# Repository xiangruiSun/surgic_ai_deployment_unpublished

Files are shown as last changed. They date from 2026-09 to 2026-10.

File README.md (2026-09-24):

# Autonomous Suturing on the dVRK: from SurgicAI policies to a real PSM

> 📄 **Draft paper (prepared for publication, not yet peer reviewed):**
> [*Autonomous Suturing Task: From Hierarchical Policies in Simulation to a Guarded Needle-Handling Pipeline on a Real dVRK*](paper/surgical_rl_draft.pdf)
> — Xiangrui Sun‡, Jiaming Wen‡, Adnan Munawar\*, Anqi Liu\* (‡equal contribution, co-first authors; \*corresponding authors). Sources and figures in [`paper/`](paper/README.md).

This repository takes the reinforcement-learning suturing policies of
[SurgicAI](https://github.com/surgical-robotics-ai/SurgicAI) (NeurIPS 2024) and
runs them on a real da Vinci Research Kit PSM. It contains the real-robot
deployment, the grasp calibration, the simulation environments used to train
and retrain the policies, and the draft paper.

## The pipeline

```text
 PERCEPTION (real endoscope)                        separate repository, see below
   ECM RGB ─► Depth Anything V2 (sim-fine-tuned, metric) ─► depth
   RGB + mask + depth ─► FoundationPose ─► needle pose  ᶜT_N
   ArUco marker on the PSM shaft ─► hand-eye  ᴱT_C

 GRASP TARGET                                       deploy/surgicai_rl_deploy/calib/
   coarse:  ᴱT_C · ᶜT_N · T_grasp   (needle point 30° along the arc, not the mesh origin)
   fine:    + Bernstein residual field learned from taught grasps (affine → degree n)
   refuses outside the calibrated box, on a pose flip, or on changed conventions

 REAL-ROBOT SEQUENCE                                deploy/run_pipeline.py
   precheck (fail-closed) ─► stage ─► approach ─► descend 7 mm ─► settle ─► close jaw
        ─► observe ─► operator gate ─► lift 1.5 cm ─► transport (via point) ─► place ─► hold
   approach:  RL checkpoint (through the verified contract) or D2 SE(3) servo
   abort:     hold the last command, never open the jaw

 SIMULATION                                         src/SurgicAI/RL/ + SurgicAI fork
   AMBF + SRC ─► SurgicAI subtask envs ─► TD3+HER+BC policies ─► checkpoints
   hierarchical 5-stage chain replicated on ROS 2 / AMBF 3 (11/20 full sutures, paper: 52%)
```

The same `GraspLiftSequencer` drives both the real arm and the AMBF grasp-and-lift
environment, so what is rehearsed in simulation is the code that runs on the robot.

## Where things are

| Part | Location | Notes |
|---|---|---|
| Real-robot pipeline | [`deploy/`](deploy/) | ROS 2 entry points, phase machine, safety, tools; 588 tests with no ROS, robot or checkpoint |
| Full pipeline guide | [`deploy/README_GRASP_LIFT.md`](deploy/README_GRASP_LIFT.md) | stage → … → place, operator gate, safety envelope |
| Approach-only guide | [`deploy/README.md`](deploy/README.md) | `run_approach.py`, frame modes, contract |
| Grasp calibration | [`deploy/README_CALIBRATION.md`](deploy/README_CALIBRATION.md) | FoundationPose + hand-eye + Bernstein residual |
| Simulation / training | [`src/SurgicAI/RL/`](src/SurgicAI/RL/) | Approach and GraspLift envs, TD3/SAC/PPO(+BC,+HER), curriculum |
| Retraining plan | [`src/SurgicAI/RL/RETRAINING.md`](src/SurgicAI/RL/RETRAINING.md) | what retraining buys, and what it does not |
| Needle model | [`asset/`](asset/) | 20 mm, 135° needle STL used for pose estimation |
| Draft paper | [`paper/`](paper/) | PDF, LaTeX, figure script, rehearsal traces |
| Hierarchical replication | [xiangruiSun/SurgicAI @ `jin-hierarchical-repro`](https://github.com/xiangruiSun/SurgicAI/tree/jin-hierarchical-repro) | Jin Wu's 5-stage pipeline on ROS 2; needs the full SurgicAI tree and the old SRC |
| Perception (DA, FP) | [suturing-policy-sim2real](https://github.com/18244241528jm-cpu/suturing-policy-sim2real) | Depth Anything fine-tuning, FoundationPose, first-frame gate |

## Things you must know before running anything

These were each found the hard way. Every RL result taken before they were fixed
is void. Details are in the paper (Sec. V) and in `deploy/README_GRASP_LIFT.md`.

1. **Roll branch.** SurgicAI puts roll in **(−2π, 0]**, not SciPy's [−π, π].
   With the wrong branch the upstream Approach policy reproduces 0/25 of its own demonstrations.
2. **Action scale is 1.0 mm / 3°.** The environment metadata's 0.5 mm / 2° is
   the demonstrations' scale, not the policy's. The old 1.5 mm was wrong.
3. **Open-loop observation.** The network sees the integrated *command*, never
   `measured_cp`. Feeding it the measured pose drops Approach to 6/25 on a lagging arm.
4. **The trained goal is 7 mm short of the needle.** The `descend` phase covers
   the last 7 mm; the policy never learned it.
5. **Staging, not retraining.** The real task is outside the policy's trained
   support (0/400 placements). A computed staging move puts all 400/400 inside it.
6. **Deadband.** The PSM ignores small setpoints: 0.4 mm moved it not at all, and
   2 mm moved it 1.947 mm. Measure the deadband with `tools/poke_arm.py` and pass `--min-command-mm`.
7. **Jaw sign.** On the dVRK, a negative jaw angle means squeeze. There is no grasp sensor, so
   jaw evidence is logged with `grasp_verified=false` and the default gate is manual.
8. **QoS.** Subscriptions are BEST_EFFORT. A RELIABLE subscriber misses `jaw/measured_js`.

## Install

Deployment host: Ubuntu 22.04, ROS 2 Humble, Python 3.10.

```bash
git clone <this repository> surgical-rl
cd surgical-rl/deploy
python3 -m venv --system-site-packages .venv-deploy   # keeps rclpy visible
source .venv-deploy/bin/activate
pip install -r requirements-deploy.txt                 # CPU torch is enough
pip install pytest && python3 -m pytest tests -q       # expect 588 passed
```

Checkpoints are not in Git:

```bash
bash tools/fetch_upstream_checkpoints.sh     # upstream Approach + Place, SHA-256 verified
# R6 (r6_unified_single_goal_yaw15_seed1_final.zip) comes from the team; place it under models/rl/
```

Simulation and training need AMBF, the SRC and `requirements/simulation.txt`.
Install a CUDA PyTorch build first.

## Run the pipeline — in this order

All poses are **tool** poses in the frame `measured_cp` reports (`ECM`).

```bash
source /opt/ros/humble/setup.bash
cd deploy

# 0. Is the arm listening, and how big is its deadband?
python3 tools/poke_arm.py --arm /PSM1 --axis x --distance-mm 2 --execute

# 1. Empty-jaw baseline (EMPTY gripper; redo after any tool change)
python3 tools/calibrate_jaw.py --arm /PSM1 --out jaw_baseline.json --execute

# 2. Rehearse offline, including the failures
python3 tools/offline_grasp_lift.py \
  --start-pos <x y z> --start-quat <qx qy qz qw> \
  --grasp-pos <x y z> --suture-pos <x y z> --suture-quat <qx qy qz qw> --suture-confirmed \
  --controller d2 --grasp-standoff-mm 7 --lift-sign -1 --grasp-gate evidence \
  --lag 0.5 --noise-mm 0.2
#   also try: --empty-gripper, --drop-at-step N, --deadband-mm 1.0 --min-command-mm 1.2

# 3. Dry run on the robot (publishes nothing)
python3 run_pipeline.py --grasp-pos <x y z> --suture-pos <x y z> --suture-quat <q> \
  --jaw-baseline jaw_baseline.json --trace dryrun.jsonl

# 4. Empty-gripper rehearsal: same command + --execute --grasp-gate always, nothing under the jaws

# 5. Live, with a human on the gate and a hand on the e-stop
python3 run_pipeline.py --grasp-pos <x y z> --suture-pos <x y z> --suture-quat <q> \
  --suture-confirmed --controller d2 --interface move_cp --rate 2 \
  --lift-sign -1 --jaw-baseline jaw_baseline.json --min-command-mm <measured> \
  --grasp-gate manual --trace live.jsonl --execute
```

To use the RL policy on the approach leg, add `--controller rl --model <zip> --stage`.
To take the grasp target from vision instead of typing it, add
`--needle-pose <FoundationPose estimate> --grasp-calibration <model.json>`
(see `deploy/README_CALIBRATION.md`).

## Useful tools (`deploy/tools/`)

| Tool | Question it answers |
|---|---|
| `verify_contract.py` | Does our observation builder reproduce the checkpoint's stored observations? |
| `replay_demos.py --compare` | Does a checkpoint work through this loop, at which action scale? |
| `profile_checkpoint.py` | What support was the checkpoint trained on? |
| `workspace_spec.py` | Is the task inside the support, and what staging move fixes it? |
| `offline_grasp_lift.py` | Does the whole sequence complete on a lagging, noisy, deadbanded arm? |
| `poke_arm.py` | Does the arm move at all, and what is its deadband? |
| `residual_structure.py` | What should the grasp residual look like before collecting data? |
| `collect_grasp_calibration.py` / `fit_grasp_calibration.py` | Plan, audit and fit a calibration session |

## Status

| | |
|---|---|
| Hierarchy in simulation (ROS 2) | 11/20 full sutures; published result 52% |
| Upstream Approach through our loop | 45/50 of its own demos (published 96 ± 6%) |
| R6 through our loop | 46/50 at 1.0 mm / 3° |
| Full sequence, offline | completes at arm lag 0 / 0.5 / 0.7, final error 0.06–0.10 cm |
| Real robot | bring-up, dry runs, deadband found and handled. **No closed-loop grasp completed yet** |
| Grasp calibration | 10 hardware samples, none usable: eyeballed poses, plus a ~43 mm constant frame offset still to resolve |

## License

MIT for the code in this repository. AMBF, SRC, SurgicAI, FoundationPose, Depth
Anything, meshes and external checkpoints follow their own licenses.

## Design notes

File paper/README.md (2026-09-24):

# Draft paper — Autonomous Suturing Task

> **DRAFT, prepared for publication. Not peer reviewed.** Results, figures and
> text are preliminary and will change. Items marked in red in the PDF
> (`[...]`) are still open.

**[Read the PDF → `surgical_rl_draft.pdf`](surgical_rl_draft.pdf)**

*Autonomous Suturing Task: From Hierarchical Policies in Simulation to a Guarded
Needle-Handling Pipeline on a Real dVRK* — Xiangrui Sun‡, Jiaming Wen‡,
Adnan Munawar\*, Anqi Liu\* (‡equal contribution, co-first authors;
\*corresponding authors).

## What is in it

| Section | Where the work lives |
|---|---|
| Hierarchical SurgicAI pipeline re-run on ROS 2 / AMBF 3 (11/20 full sutures vs. 52% published) | `xiangruiSun/SurgicAI`, branch `jin-hierarchical-repro`, `RL/HIERARCHICAL_README.md` |
| Perception: sim-fine-tuned Depth Anything V2, FoundationPose, ArUco hand-eye | perception pipeline (Jiaming) |
| Deployment contract, the three defects, staging, phase machine, deadband | `deploy/` |
| Two-stage grasp calibration and first hardware samples | `deploy/surgicai_rl_deploy/calib/` |

## Files

```
surgical_rl_draft.pdf    the draft
surgical_rl_draft.tex    source (ieeeconf); needs colors.tex, ieeeconf.cls, figures/
figures/*.tikz           pipeline and phase-machine diagrams (drawn in LaTeX)
figures/*.pdf|png        data figures
make_figures.py          regenerates every data figure
runs/*.json              offline rehearsal traces used by the figures
```

## Rebuild

```bash
# figures (needs numpy, scipy, matplotlib; uses ../deploy)
python3 make_figures.py

# rehearsal traces, if you want to regenerate runs/ too (run from ../deploy)
python3 tools/offline_grasp_lift.py \
  --start-pos -0.05639860616831881 0.03366166453830251 0.024455994074878362 \
  --start-quat 0.23319925218484056 0.4267863636861243 -0.23588767438897446 0.841325450478807 \
  --grasp-pos -0.050726357 0.015332369 0.049514053 \
  --suture-pos -0.040 0.005 0.040 --suture-quat 0 0 0 1 --suture-confirmed \
  --controller d2 --lift-sign -1 --grasp-gate evidence --grasp-standoff-mm 7 \
  --noise-mm 0.2 --seed 1 --lag 0.5 --json-out sl0.5.json
#   deadband runs: add --stage --contract approach_upstream --deadband-mm 1.0
#   --descend-success-trans-cm 0.2 [--min-command-mm 1.2]

# paper
pdflatex surgical_rl_draft.tex && pdflatex surgical_rl_draft.tex
```

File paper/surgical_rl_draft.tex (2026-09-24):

%%%%%%%%%%%%%%%%%%%%%%%%%%%%%%%%%%%%%%%%%%%%%%%%%%%%%%%%%%%%%%%%%%%%%%%%%%%%%%%%
%2345678901234567890123456789012345678901234567890123456789012345678901234567890
%        1         2         3         4         5         6         7         8

\documentclass[letterpaper, 10 pt, conference]{ieeeconf}  % Comment this line out if you need a4paper

%\documentclass[a4paper, 10pt, conference]{ieeeconf}      % Use this line for a4 paper

\IEEEoverridecommandlockouts                              % This command is only needed if
                                                          % you want to use the \thanks command

\overrideIEEEmargins                                      % Needed to meet printer requirements.

\usepackage{graphicx}
\usepackage{amsmath}
\usepackage{amssymb}
\usepackage{booktabs}
\usepackage{multirow}
\usepackage{xcolor}
\usepackage{cite}
\usepackage{eso-pic}
\usepackage{tikz}
\usetikzlibrary{positioning,arrows.meta,fit,backgrounds,calc,shapes.geometric}
\input{colors.tex}
\usepackage[hidelinks]{hyperref}

\graphicspath{{figures/}}
\newcommand{\todo}[1]{{\color{cRed}[#1]}}

% draft banner on every page
\AddToShipoutPictureBG{%
  \AtPageUpperLeft{\raisebox{-0.9cm}{\makebox[\paperwidth]{\footnotesize\sffamily\color{cRed}%
  DRAFT \,--\, prepared for publication, not yet peer reviewed \,--\, \today}}}}

\title{\LARGE \bf
Autonomous Suturing Task:\\
From Hierarchical Policies in Simulation to a Guarded\\
Needle-Handling Pipeline on a Real dVRK
}

\author{Xiangrui Sun$^{1,\ast}$, Jiaming Wen$^{2,\ast}$, Adnan Munawar$^{1,\dagger}$, and Anqi Liu$^{3,\dagger}$% <-this % stops a space
\thanks{This work was not supported by any organization.}%
\thanks{$^{\ast}$Xiangrui Sun and Jiaming Wen contributed equally to this work (co-first authors).}% <-this % stops a space
\thanks{\textbf{Draft manuscript prepared for publication.} Results, figures and text are
        preliminary and subject to change.}%
\thanks{$^{\dagger}$Corresponding authors: Adnan Munawar {\tt\small amunawa2@jhu.edu};
        Anqi Liu {\tt\small aliu.cs@jhu.edu}.}%
\thanks{$^{1}$Xiangrui Sun and Adnan Munawar are with the Laboratory for Computational
        Sensing and Robotics, Johns Hopkins University, Baltimore, MD 21218, USA
        {\tt\small xsun97@jh.edu}}%
\thanks{$^{2}$Jiaming Wen is with \todo{affiliation}
        {\tt\small \todo{email}}}%
\thanks{$^{3}$Anqi Liu is with the Department of Computer Science,
        Johns Hopkins University, Baltimore, MD 21218, USA}%
}

\begin{document}

\maketitle
\thispagestyle{empty}
\pagestyle{empty}

%%%%%%%%%%%%%%%%%%%%%%%%%%%%%%%%%%%%%%%%%%%%%%%%%%%%%%%%%%%%%%%%%%%%%%%%%%%%%%%%
\begin{abstract}
Reinforcement-learning (RL) policies for surgical suturing are commonly trained
and scored in simulation and seldom run on a physical robot. We report our
progress in moving the hierarchical suturing policies of SurgicAI onto a da Vinci
Research Kit (dVRK). First, we re-run the original five-stage hierarchy
(Approach, Place, Insert, Regrasp, Pullout) on ROS~2 and AMBF~3 without changing
any policy or environment logic. It completes the full suture in 11 of 20
episodes, against the 52\% reported by its authors. Second, we build a perception
front end for the real endoscope. Depth Anything V2 is fine-tuned on simulated
RGB--depth pairs so that it outputs metric depth, and FoundationPose uses that
depth to estimate the pose of the needle. An ArUco-based hand-eye calibration
improves PSM localization from about 5\,cm to 5--10\,mm. Third, we deploy the
released policies on a real PSM through an explicit observation--action
contract. Running the policies against their own demonstrations exposed three
silent mismatches between the training environment and a straightforward
deployment: the Euler-angle branch, the action scale, and whether the
observation is open- or closed-loop. Once these are fixed, the released Approach
checkpoint reproduces 45 of its 50 demonstrations. We also show that the gap
between the training workspace and the real task can be closed by staging the
start pose rather than by retraining, and we describe a guarded phase machine
that takes the arm from staging through grasp, lift and transport to the suture
entry pose. Finally, we propose a two-stage grasp calibration, in which a
Bernstein residual field corrects a coarse FoundationPose-based grasp target,
and report the first ten hardware samples. They reveal a constant offset of
about 43\,mm that must be removed before any fit.
\end{abstract}

%%%%%%%%%%%%%%%%%%%%%%%%%%%%%%%%%%%%%%%%%%%%%%%%%%%%%%%%%%%%%%%%%%%%%%%%%%%%%%%%
\section{INTRODUCTION}

Suturing is the canonical benchmark for surgical autonomy. It is long-horizon,
contact-rich, and needs millimetre precision on a thin, curved,
near-symmetric object. Simulation platforms built on AMBF~\cite{munawar2019ambf}
and the Surgical Robotics Challenge (SRC)~\cite{munawar2022src} have made the
task learnable. SurgicAI~\cite{wu2024surgicai} splits it into five subtasks and
learns a policy for each one. A high-level policy then sequences them, and the
full chain succeeds far more often with this hierarchy than with a flat policy.
Physical deployments remain rare. Orbit-Surgical transferred a policy to a real
dVRK at 50\% on needle lift~\cite{yu2024orbit}, and a recent review describes the
field as ``mature at the simulation stage but \ldots\ preclinical''~\cite{review2026rl}.

This draft reports what it has taken so far to move the SurgicAI policies onto a
real dVRK~\cite{kazanzides2014dvrk} Patient Side Manipulator (PSM). We emphasize
where the transfer actually broke. Much of the gap turned out not to be
``sim-to-real'' in the usual sense. The cause was usually an unstated convention
in the training code that a deployment has to reproduce exactly. Our
contributions are:
\begin{enumerate}
\item A \emph{replication} of the hierarchical suturing pipeline on ROS~2/AMBF~3.
      The environment and policy code are unchanged, and the chained success rates
      are consistent with the published ones (Sec.~\ref{sec:hier}).
\item A \emph{perception front end} for the real endoscope: sim-supervised metric
      depth, FoundationPose needle tracking and hand-eye registration of the PSM
      (Sec.~\ref{sec:perception}).
\item A \emph{verified deployment contract} for the released checkpoints. It
      identifies three defects that invalidate a straightforward deployment, and
      a staging solve that places any real grasp inside the trained support
      (Sec.~\ref{sec:deploy}).
\item A \emph{guarded real-robot phase machine} and the hardware findings from
      bringing it up, including the PSM position deadband
      (Sec.~\ref{sec:sequence}).
\item A \emph{two-stage grasp calibration} whose structure is predicted from the
      dVRK kinematics before any data is collected, together with the first
      hardware samples (Sec.~\ref{sec:calib}).
\end{enumerate}
Fig.~\ref{fig:overview} shows how the components fit together.

\begin{figure*}[t]
  \centering
  \resizebox{\textwidth}{!}{\input{figures/overview.tikz}}
  \caption{System overview. \emph{Simulation}: the SurgicAI hierarchy in
  AMBF/SRC, re-run on ROS~2; the same simulator provides RGB--depth pairs for
  depth fine-tuning. \emph{Perception}: on the real dVRK, fine-tuned Depth
  Anything V2 supplies metric depth to FoundationPose, and an ArUco hand-eye
  calibration registers the camera to the PSM. \emph{Real robot}: the perceived
  needle pose becomes a coarse grasp target, which a learned residual corrects.
  The released checkpoints drive the arm only through a verified contract layer
  and a guarded phase machine.}
  \label{fig:overview}
\end{figure*}

%%%%%%%%%%%%%%%%%%%%%%%%%%%%%%%%%%%%%%%%%%%%%%%%%%%%%%%%%%%%%%%%%%%%%%%%%%%%%%%%
\section{RELATED WORK}

\textbf{Learning suturing in simulation.} AMBF~\cite{munawar2019ambf} and the
SRC~\cite{munawar2022src} provide a dVRK-faithful suturing scene with a needle,
a phantom and entry/exit targets. SurgicAI~\cite{wu2024surgicai} benchmarks RL
and imitation-learning algorithms on its subtasks. TD3~\cite{fujimoto2018td3}
with hindsight experience replay~\cite{andrychowicz2017her} and a
behavior-cloning term reaches roughly 96\% on single subtasks. The hierarchical
composition reaches 52\% on the full chain, compared with 15\% for a flat policy.
Orbit-Surgical~\cite{yu2024orbit} trains in GPU-parallel simulation and reports
a physical transfer.

\textbf{Sim-to-real.} Domain randomization is the principal mitigation.
Xie~\emph{et~al.}~\cite{xie2022randomization} find that randomizing one
dimension at a time transfers more reliably than randomizing everything at once.
We adopt their stopping rule for a retraining curriculum, but our results
suggest that the first-order transfer problems for these policies are contract
mismatches rather than visual or dynamic gaps.

\textbf{Needle pose and robot calibration.} Markerless needle pose tracking
reaches roughly 1\,mm~\cite{chiu2022needle}. FoundationPose~\cite{wen2024foundationpose}
provides model-based 6D pose from RGB-D with no object-specific training.
Kinematic error on the dVRK is dominated by joint offsets and cable
effects~\cite{hwang2020calibrating}. Hwang~\emph{et~al.} need a recurrent model
because hysteresis is not a function of position. We build on the two-stage
calibration of Xiao~\emph{et~al.}~\cite{xiao2022delta}, a coarse geometric
model followed by a Bernstein-polynomial residual.

%%%%%%%%%%%%%%%%%%%%%%%%%%%%%%%%%%%%%%%%%%%%%%%%%%%%%%%%%%%%%%%%%%%%%%%%%%%%%%%%
\section{HIERARCHICAL SUTURING IN SIMULATION}
\label{sec:hier}

\subsection{The SurgicAI hierarchy}
The hierarchy has a high-level PPO policy with a 35-dimensional observation and
five discrete actions. Each action selects a low-level TD3+BC policy
(Table~\ref{tab:stages}), and each low-level policy runs for at most 200 steps.
Every low-level policy is goal-conditioned on a 7-DoF target made of position,
roll--pitch--yaw and jaw. It outputs a normalized increment that is scaled by a
per-task step size and integrated into the commanded pose.

\begin{table}[t]
\caption{Stages of the hierarchy, as used by the low-level controller.}
\label{tab:stages}
\centering\footnotesize
\setlength{\tabcolsep}{3.5pt}
\begin{tabular}{@{}clll@{}}
\toprule
Task & Stage & Arm & Completion side effect \\
\midrule
1 & Approach & PSM2 & close jaw, attach needle \\
2 & Place    & PSM2 & re-sync goal from measured pose \\
3 & Insert   & PSM2 & -- \\
4 & Regrasp  & PSM1 & PSM1 grasps, PSM2 opens \\
5 & Pullout  & PSM1 & episode terminates with success \\
\bottomrule
\end{tabular}
\end{table}

\subsection{Porting to ROS~2 and AMBF~3}
The original code targets ROS~1 Noetic, AMBF~2.0 and a 2024 snapshot of the SRC.
We run it unchanged on Ubuntu~24.04 with ROS~2 Jazzy by adding three pieces.
The first is a minimal \texttt{rospy} shim built on the ROS abstraction layer
that the ROS~2 AMBF client already uses. The second is a set of repository-relative
model and config paths. The third is a set of runtime fixes for three problems
in the ROS~2 AMBF client that only the old scene exposes: sensors that do not
accept the middleware handle, incremental DDS discovery that silently misses
objects, and name lookups made ambiguous by ghost objects. Checkpoints saved
under Python~3.8 load under Python~3.12 with Stable-Baselines3~2.2.1 and give
identical predictions once training-only pickles are skipped.

\subsection{Results}
The high-level PPO checkpoint has not been released. We therefore sequence the
five stages in order and allow up to two retries per stage. This stands in for
a high-level policy that keeps selecting a stage until it completes. The
low-level checkpoints are recovered from the repository history. Fig.~\ref{fig:hier}
compares 20 episodes (seed 10) with Table~3 of~\cite{wu2024surgicai} (100
episodes; ``Regrasp'' is called ``Handoff'' there). The full chain succeeds in
11/20 episodes (0.55), against 0.52 in the paper. All nine failures reach the
800-step low-level limit: seven in Pullout and two in Place. The mean number of
steps per completed stage is 139 for Approach, 59 for Place, 88 for Insert, 154
for Regrasp and 111 for Pullout. We also found a bookkeeping bug.
\texttt{info["is\_success"]} is set when Pullout completes but is overwritten
later in the same function, so it is never true. Success is therefore counted
from \texttt{terminated}, which is also what the high-level reward uses.

\begin{figure}[t]
  \centering
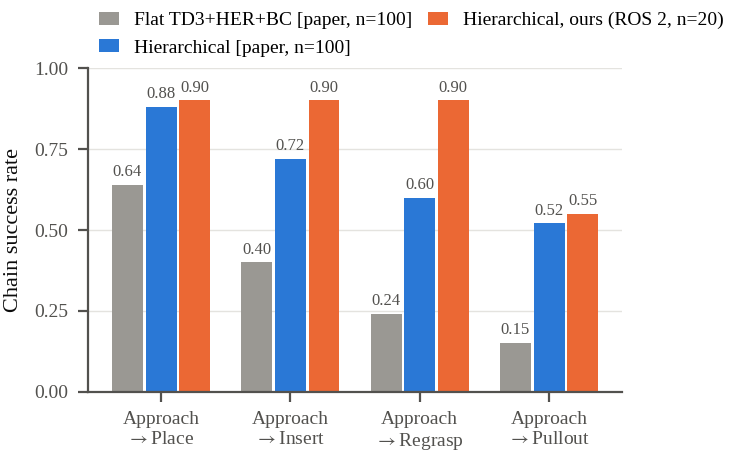
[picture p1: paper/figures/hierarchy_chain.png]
  
  \caption{Chained success from Approach to each later stage. Grey and blue:
  flat and hierarchical results from~\cite{wu2024surgicai} ($n{=}100$); the flat
  TD3+HER baseline, 0.00 throughout, is omitted. Orange: our replication on
  ROS~2/AMBF~3 ($n{=}20$), with scripted stage sequencing in place of the
  unreleased high-level policy. With $n{=}20$ the 95\% interval on 0.55 is about
  $\pm$0.22.}
  \label{fig:hier}
\end{figure}

The intermediate chains exceed the published values (0.90 against 0.72 and
0.60). The likeliest reason is our stage sequencing: it always retries rather
than letting a learned high-level policy choose, and a retry can recover a
stage that a policy would have abandoned. Table~\ref{tab:scenes} shows why the
policies cannot run on the newer SRC scenes without adaptation. The observations
are absolute poses in the PSM base frame, and the base-to-needle offset changes
by several centimetres between the old and new worlds.

\begin{table}[t]
\caption{What the policies assume, old vs.\ current SRC (static check).}
\label{tab:scenes}
\centering\footnotesize
\setlength{\tabcolsep}{3pt}
\begin{tabular}{@{}p{0.27\columnwidth}p{0.31\columnwidth}p{0.34\columnwidth}@{}}
\toprule
Assumption & Old SRC (policies) & SRC v2.x \\
\midrule
middleware & ROS~1 & ROS~2 \\
needle topic & \texttt{env/Needle} & \texttt{env/phantom/Needle} \\
FK module & \texttt{psmFK} & removed \\
PSM1 base & $(1.0,1.346,1.350)$, 0.1-scaled & $(0.131,0.397,0.878)$\,m \\
needle spawn & hard-coded world pose & differs per phantom \\
\bottomrule
\end{tabular}
\end{table}

%%%%%%%%%%%%%%%%%%%%%%%%%%%%%%%%%%%%%%%%%%%%%%%%%%%%%%%%%%%%%%%%%%%%%%%%%%%%%%%%
\section{PERCEPTION ON THE REAL dVRK}
\label{sec:perception}

\subsection{Simulation-Based Adaptation of Depth Anything for Metric Depth Estimation}
We first evaluated the pretrained Depth Anything V2 model~\cite{yang2024depthv2}
on images from the simulated suturing environment without task-specific
fine-tuning. In this baseline configuration the model produced relative depth
estimates, normalized to a range of approximately 0 to 1, rather than
physically meaningful metric depth. The pretrained model had also never seen
the visual characteristics of the surgical scene: the surgical instruments, the
tissue phantom and the endoscopic imaging conditions. Its depth predictions
therefore had substantial errors and were not accurate enough for downstream
robotic perception and manipulation.

To adapt the model to the surgical domain and make it predict absolute depth
in meters, we fine-tuned it on data generated from the AMBF-based suturing
simulation environment. Collecting equivalent supervised training data directly
from the physical dVRK is difficult because the real endoscopic camera provides
no dense ground-truth depth. The simulator is therefore an effective source of
paired RGB and metric-depth data that preserves the visual and geometric
characteristics of the target surgical scenario.

During data collection, RGB images were acquired from the simulated endoscopic
camera and used as inputs to the depth estimation network. For each RGB frame,
the AMBF simulator also provided a corresponding three-dimensional point cloud.
The 3-D points were transformed into the camera coordinate system and projected
onto the image plane to build a dense per-pixel depth map in meters, which was
used as ground-truth supervision for fine-tuning. Each training sample was thus
an RGB image of the simulated suturing scene paired with its geometrically
derived metric-depth map.

After task-specific fine-tuning, the model estimated depth substantially better
within the suturing environment. Instead of relative depth, the adapted model
predicts depth directly in metric units and reproduces the spatial structure of
the surgical scene more accurately. This simulation-based training strategy is
a practical way to obtain dense depth supervision that is difficult to acquire
on the physical dVRK, and it adapts the pretrained depth estimator to the
geometric and visual characteristics of robot-assisted suturing.
\todo{Jiaming: add the quantitative depth error before and after fine-tuning
(e.g.\ AbsRel, RMSE in mm) and the size of the training set.}

\subsection{FoundationPose Tracking on the Real dVRK System}
\todo{unfinished -- Jiaming: add experimental results and explain the observed
tracking failure.}
FoundationPose~\cite{wen2024foundationpose} was used to estimate the poses of the
PSM and the surgical needle on the physical dVRK. The method requires an RGB
image, an object mask and a depth map as inputs. Because the dVRK endoscope
provides no direct depth measurements, the depth maps were generated with the
fine-tuned Depth Anything model.

The pipeline tracked the surgical needle reliably. Tracking of the PSM was less
stable and had larger pose errors. When tracking the PSM \todo{\ldots}

In simulation, the complete path from RGB through Depth Anything, FoundationPose
and a first-frame physical-plausibility gate to a frozen needle goal passed the
gate on 40/40 captures. A Reach controller driven by these goals succeeded in
29/30 episodes. \todo{Confirm which goal source (GT vs.\ FP) the 29/30 refers
to; these are historical reference runs and were not re-run for this draft.}
Needle yaw in the curriculum is capped at $\pm 30^\circ$ because the pose audit
was reliable at $20^\circ$ but produced near-$180^\circ$ flips at $40^\circ$.
Section~\ref{sec:workspace} shows that this cap, not the policy's trained
workspace, is what limits the task.

\subsection{Hand-Eye Calibration for PSM Localization}
To obtain an independent estimate of the PSM pose in the camera frame, we
performed hand-eye calibration with the dVRK camera registration framework. An
ArUco marker~\cite{garrido2014aruco} was mounted on the PSM shaft approximately
70\,mm from the instrument tip. The camera was positioned so that the marker
stayed near the center of the image, and the PSM was moved through multiple
poses while the marker remained visible. The recorded robot and marker poses
were then used to estimate the transformation between the PSM and camera frames.

This calibration improves the PSM localization accuracy from approximately 5\,cm
to 5--10\,mm. The resulting pose estimate is an additional reference that can
be fused with the FoundationPose estimate, for example with a Kalman filter, to
make PSM tracking more robust. Section~\ref{sec:calib} explains why hand-eye
error of this size is exactly affine in position and can therefore be absorbed
by the grasp calibration.

%%%%%%%%%%%%%%%%%%%%%%%%%%%%%%%%%%%%%%%%%%%%%%%%%%%%%%%%%%%%%%%%%%%%%%%%%%%%%%%%
\section{DEPLOYING THE RELEASED POLICIES}
\label{sec:deploy}

We deploy three checkpoints: the released SurgicAI Approach and Place policies
(TD3+HER+BC) and R6, a locally retrained single-goal Approach policy. Deployment
is inference-only. It uses a CPU-loaded $3{\times}256$ actor and the arm's
\texttt{measured\_cp} in the ECM frame. It does not use AMBF or any training code.

\subsection{The observation--action contract}
The contract is decoded from the checkpoints themselves.

\emph{Observation}: $o=[a,\,d,\,d{-}a]\in\mathbb{R}^{21}$, where $a$ and $d$ are
the achieved and desired poses. Each is written as position in centimetres,
RPY in radians (extrinsic $xyz$, KDL \texttt{GetRPY}), and jaw normalized to
$[0,1]$. Our observation builder reproduces all 502 observations stored in the
R6 checkpoint exactly.

\emph{Action}: $u\in[-1,1]^7$ is integrated as
$c_{t+1}=c_t+u\odot s$. The step $s$ is in \emph{metres} and radians while the
observation is in centimetres, and this asymmetry is part of the contract.

\subsection{Three silent defects}
A deployment can satisfy all of the above and still fail. We replayed each
checkpoint from its own demonstration starts against a kinematic arm model, and
this found three further defects. Together they invalidate every hardware RL
comparison we had made before fixing them.

\emph{1) The roll branch.} A rotation matrix is branch-invariant, but its RPY
triple is not. SciPy returns roll in $[-\pi,\pi]$, whereas SurgicAI's
\texttt{Frame2Vec} maps it into $(-2\pi,0]$. All stored goal rolls in the
released checkpoints lie outside $\pm\pi$, and none lies outside $(-2\pi,0]$.
With the SciPy convention, upstream Approach reproduces 0/25 demonstrations.
The geometric servo was never affected because it uses only relative
rotation. This is why ``the servo works and RL does not'' looked like a
statement about policy quality for so long.

\emph{2) Two action scales.} The environment metadata stores 0.5\,mm\,/\,2$^\circ$,
the scale the \emph{demonstrations} integrate at, and fitting the
demonstrations recovers this value exactly. The training and evaluation scripts,
however, hard-code 1.0\,mm\,/\,3$^\circ$, and all published success rates were
measured at that scale. Replay picks 1.0\,mm\,/\,3$^\circ$ unambiguously
(Fig.~\ref{fig:contract}a). The 1.5\,mm we had been applying came from a
utility module and was never checked against the policy.

\emph{3) Open- vs.\ closed-loop observation.} Inside a subtask, SurgicAI feeds
the network the integrated \emph{command}, never the measured pose. A perfect
arm hides the difference. For a lagging arm, feeding the measured pose drops
Approach from 25/25 to 6/25 at 30\% tracking per cycle
(Fig.~\ref{fig:contract}b). We now compute the observation from an internal
integrator seeded once, and the measured pose is used only by the guards. A
fourth defect appeared while testing this fix. The per-step safety caps were
measured against the measured pose, so they pulled the command back toward a
lagging arm on every cycle. This re-closed the loop from inside the safety
layer. The caps now bound consecutive commands, and a separate guard bounds
tracking error.

\begin{figure*}[t]
  \centering
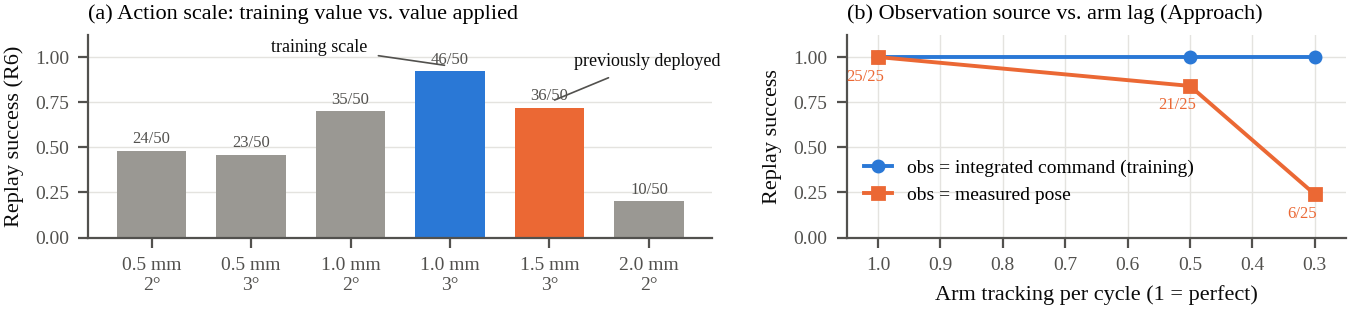
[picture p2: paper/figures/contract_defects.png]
  
  \caption{Two contract defects, measured by replaying policies from their own
  demonstration starts. (a) R6 success as a function of action scale at its own
  tolerance (1\,cm\,/\,10$^\circ$, 200 steps): the training scale gives 46/50,
  and the scale previously deployed gives 36/50. (b) Upstream Approach under a
  first-order lagging arm. Feeding the measured pose instead of the integrated
  command matches the training environment only for a perfect arm.}
  \label{fig:contract}
\end{figure*}

With all three defects fixed, upstream Approach reproduces 45/50 of its
demonstrations through our loop (published $96\pm6\%$), and R6 reproduces 46/50.
We also found that the published rates use a tolerance of
0.5\,cm\,/\,\textbf{30}$^\circ$. At that tolerance Approach reproduces 25/25 and
Place 22/25. At $10^\circ$, the tolerance in the environment metadata, Place
drops to 12/25, so Place is not a precision orientation controller.

\subsection{The workspace question is a staging question}
\label{sec:workspace}
On the real task, the released Approach policy is out of distribution. The
needed start-to-goal rotation is 0--30$^\circ$, while training covered
53--97$^\circ$, and the tool-frame offset has the wrong sign in $y$. Every
unstaged RL run orbited the goal. We first expected this to require retraining
on a wider workspace. However, the demonstrated support of a goal-conditioned
policy is expressed entirely in relative quantities:
\begin{equation}
  \delta = R_s^{\top}(p_g-p_s), \qquad \theta=\angle(R_s,R_g),
\end{equation}
and both are invariant to rigid transforms. For any grasp pose
$(p_g,R_g)$ there is therefore a start pose inside the support, and it can be
solved for directly:
\begin{equation}
  R_s = R_g\,\mathrm{Rel}^{-1},\qquad p_s=p_g-R_s\,\delta^{\star},
\end{equation}
where $\mathrm{Rel}$ and $\delta^{\star}$ are the rotation and offset taken
from the support. We evaluate this on the recorded geometry of our dVRK with
400 needle placements over a $\pm3$\,mm, $\pm30^\circ$ envelope. Without
staging, 0/400 placements are in support. With staging, all 400 are, and the
staging move has a median length of 3.66\,cm and a maximum of 4.14\,cm
(Fig.~\ref{fig:workspace}). For the approach leg, the trained workspace is not
the binding constraint. The binding constraints are perception (the
$\pm30^\circ$ yaw cap), reachability and Place.

\begin{figure}[t]
  \centering
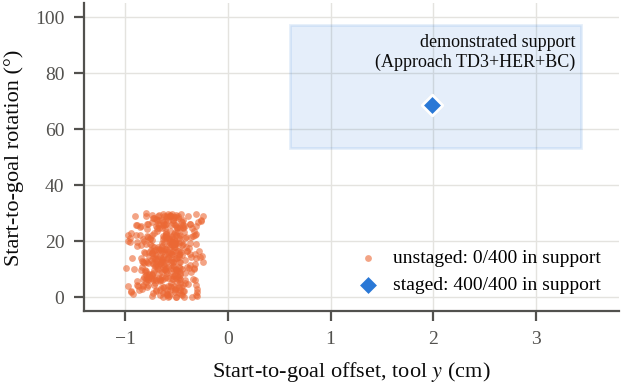
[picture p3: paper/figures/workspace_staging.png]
  
  \caption{Relative start-to-goal geometry for 400 needle placements on the
  recorded dVRK task, against the demonstrated support of the upstream
  Approach policy. Staging moves every placement to the same point inside the
  support. It is a 3.7\,cm median move, well inside the 8\,cm path-radius
  guard. Computed with \texttt{deploy/tools/workspace\_spec.py}.}
  \label{fig:workspace}
\end{figure}

\subsection{The trained goal is 7\,mm short of the needle}
SurgicAI builds the Approach goal as
$\mathbf{T}_N(\phi)\,\mathrm{Trans}(0,0,7\,\mathrm{mm})\,R_{\mathrm{flip}}$. It is
the grasp point on the arc, backed off 7\,mm along the tool axis with the jaws
pointing at it. In simulation the grasp is then faked by attaching the needle
wherever the jaws are, so no trained motion ever covers the last 7\,mm. On
hardware, closing the jaw at the policy goal would close on empty space. We
therefore add a \emph{descend} phase that covers the standoff at 0.5\,mm per
cycle along the jaw axis with the orientation frozen. It is the slowest motion
in the sequence because it is the only one that can disturb the needle before
the needle is held.

%%%%%%%%%%%%%%%%%%%%%%%%%%%%%%%%%%%%%%%%%%%%%%%%%%%%%%%%%%%%%%%%%%%%%%%%%%%%%%%%
\section{A GUARDED NEEDLE-HANDLING SEQUENCE}
\label{sec:sequence}

\subsection{Phase machine}
Fig.~\ref{fig:phases} shows the sequence. The task is specified by three
\emph{tool} poses in the frame of \texttt{measured\_cp}: the start pose, read
from the arm; the grasp pose; and the suture pose, at which the needle sits
angled at the entry point. Needle-frame targets cannot be used, because after a
blind grasp the needle-in-jaw transform is unknown. The approach leg may use the
RL policy or a staged SE(3) servo (D2). Transport uses the servo. The Place
policy runs in shadow mode only: on the recorded geometry it reports itself out
of distribution as soon as transport begins, which is consistent with its
replay results above.

\begin{figure}[t]
  \centering
  \resizebox{\columnwidth}{!}{\input{figures/phases.tikz}}
  \caption{The real-robot phase machine. Staging places the arm inside the
  policy's support, and \emph{descend} covers the 7\,mm standoff that training
  never covers. The gate is either a human confirmation (default) or jaw
  evidence. Transport goes through a via point one lift height above the
  suture pose, so the needle cannot pass below the tissue plane. The suture
  pose is corrected for where the jaws actually closed.}
  \label{fig:phases}
\end{figure}

\textbf{No grasp sensor.} The simulator attaches the needle by fiat, and
hardware has no equivalent. Grasp evidence comes from two indirect channels:
the jaw-angle residual relative to an empty-jaw baseline, and jaw effort, which
not every arm publishes. Both are logged with \texttt{grasp\_verified=false}.
The default gate is manual. Jaw units are a further sim-to-real trap: on the
dVRK negative jaw angles mean squeeze, so mapping ``closed'' to 0 applies no
tendon tension at all. The grip is therefore commanded on a separate channel
(default $-15^\circ$).

\textbf{Suture-pose compensation.} A suture pose taught by jogging the arm
while it holds the needle encodes how the needle sat in the jaws at that
moment. Let $W$ be the needle pose, $E$ its required pose and $G$ the grasp.
The tool must reach $S=E\,W^{-1}G$. A pose $S_t$ taught with grasp $G_t$
therefore transfers to an actual grasp $G_a$ as
\begin{equation}
  S_a = S_t\,G_t^{-1}\,G_a ,
\end{equation}
in which neither $E$ nor $W$ appears. Corrections larger than 10\,mm abort,
because a correction that large most likely means the needle moved.

\textbf{Safety envelope.} A fail-closed precheck verifies reachability, the
workspace and operator boxes, step budgets, and tolerances against the lift
distance and the deadband. The operator must state the lift sign, because
$+z$ in the ECM frame is not guaranteed to point away from the tissue. Runtime
guards cap each command at 2.5\,mm and 5$^\circ$, abort on 1.5\,cm of tracking
lag or on a \texttt{measured\_cp} older than 0.25\,s, and never open the jaw on
abort.

\subsection{Hardware bring-up findings}
\textbf{Position deadband.} During the first live staging move, the arm stayed
at 0.25\,cm error for 49 cycles without moving at all. A single hand-published
2\,mm setpoint moved it 1.947\,mm. The loop, however, was publishing about
0.4\,mm per cycle, because a proportional servo shrinks its step near the goal,
and the arm ignored these commands. No existing guard detected this, since the
command never ran more than 0.4\,mm ahead of the arm. We added a minimum command
magnitude that stretches a non-zero command up to the measured deadband, along
the same direction and never past the target. The precheck now rejects any
tolerance finer than the deadband. Fig.~\ref{fig:deadband} reproduces the stall
with a deadband model and shows the fix.

\begin{figure}[t]
  \centering
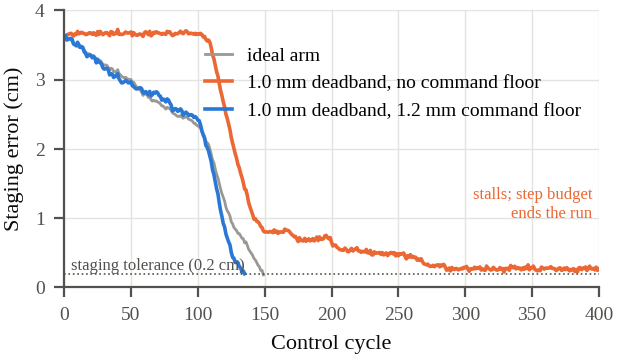
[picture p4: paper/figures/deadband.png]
  
  \caption{Staging under a 1\,mm position deadband (offline, arm lag 0.5,
  0.2\,mm pose noise). Without a command floor, the servo's shrinking steps are
  absorbed and the move stalls, as on the hardware, until the step budget ends
  the run. A 1.2\,mm floor restores convergence, and the full nine-phase
  sequence completes 0.18\,cm from the suture pose.}
  \label{fig:deadband}
\end{figure}

\textbf{Middleware.} State topics on the dVRK do not all use the same QoS. A
RELIABLE subscriber matched \texttt{measured\_cp} but not
\texttt{jaw/measured\_js}, so the jaw appeared absent even though
\texttt{ros2 topic echo} showed it publishing. All subscriptions now default to
BEST\_EFFORT. The node also refuses to execute when nothing is subscribed to
its command topic, because publishing into the void looks identical to an arm
that does not move.

\textbf{Operator interface.} On the first dry run, the gate prompt printed once
and then scrolled away under a 10\,Hz status line, so the paused arm looked
hung. The prompt now repeats and status output is throttled while waiting.
A keyword-substitution error that reached the node's untested
\texttt{main()} led to static checks. Every keyword and every parsed argument is
now checked against the real signatures using the Python AST. The deployment
package has 588 unit tests, none of which require ROS, a robot or a checkpoint.

\subsection{Offline rehearsal of the full sequence}
Every change is rehearsed against a kinematic arm model with first-order lag,
pose noise, a jaw model and an optional deadband, using the recorded operator
poses. Table~\ref{tab:rehearsal} and Fig.~\ref{fig:sequence} show the full
sequence with the D2 approach controller and the 7\,mm standoff.

\begin{table}[t]
\caption{Offline rehearsal of the full sequence on the recorded task
(D2 approach, 7\,mm standoff, 0.2\,mm noise, seed 1).}
\label{tab:rehearsal}
\centering\footnotesize
\begin{tabular}{@{}lccc@{}}
\toprule
Arm lag per cycle & 0.0 & 0.5 & 0.7 \\
\midrule
Cycles to completion & 166 & 241 & 337 \\
Final error to suture pose (cm) & 0.064 & 0.076 & 0.098 \\
Precheck & pass & pass & pass \\
\bottomrule
\end{tabular}
\end{table}

\begin{figure*}[t]
  \centering
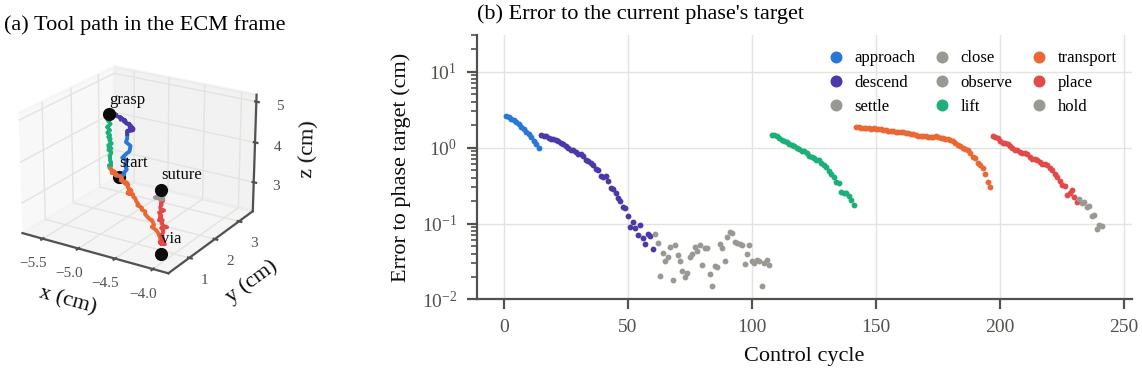
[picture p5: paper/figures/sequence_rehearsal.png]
  
  \caption{One rehearsal of the full sequence (arm lag 0.5). (a) Measured tool
  path in the ECM frame, colored by phase. (b) Error to each phase's own target.
  Every motion phase converges before the next begins, and the jaw phases
  (grey) hold position while the gate is evaluated.}
  \label{fig:sequence}
\end{figure*}

%%%%%%%%%%%%%%%%%%%%%%%%%%%%%%%%%%%%%%%%%%%%%%%%%%%%%%%%%%%%%%%%%%%%%%%%%%%%%%%%
\section{VISION-GUIDED GRASP CALIBRATION}
\label{sec:calib}

\subsection{Two stages}
The coarse stage maps a FoundationPose estimate through the hand-eye transform
to a grasp target $p_{\mathrm{nom}}={}^{E}\mathbf{T}_{C}\,{}^{C}\mathbf{T}_{N}\,
\mathbf{t}_{\mathrm{grasp}}$. The fine stage learns the residual
$r=p_{\mathrm{grasp}}-p_{\mathrm{nom}}$ from grasps taught by hand, following
Xiao~\emph{et~al.}~\cite{xiao2022delta}, with two departures. First, we use
trivariate polynomials of \emph{total} degree~$n$ in the Bernstein basis. The
constant and affine baselines are then the degree-0 and degree-1 rungs of the
same ladder. The model is frame-invariant and needs 1/4/10/20 coefficients
rather than 1/8/27/64 for the tensor-product basis. Second, the penalty is the
exact thin-plate curvature energy, whose null space is the affine functions. As
$\lambda\to\infty$ the fit therefore becomes the affine model, and choosing
$\lambda$ by leave-one-placement-out cross-validation decides whether curvature
has earned its place. The fit is linear and is solved with one QR
factorization. The convex-hull property bounds the correction anywhere in the
calibrated box, and the runtime refuses to extrapolate outside it.

\subsection{Predicted residual structure}
Before collecting any data, we propagate each error source through the dVRK DH
parameters over a 4\,cm grasping box (Fig.~\ref{fig:calib}a). Hand-eye error is
\emph{exactly} affine: $r=(R_{\mathrm{true}}R_{\mathrm{nom}}^{\top}-I)p_{\mathrm{nom}}+b$.
Offsets in the first two PSM joints rotate the whole distal chain about axes
through the base, so they are also affine. Every other geometric term leaves
less than 0.02\,mm after an affine fit, about twenty times below the
repeatability of a taught grasp. A positive result at degree $\geq2$ would
therefore be a statement about FoundationPose's learned bias, not about the
robot. Two choices matter more than the degree. The needle mesh origin is the
centre of the arc, 10.18\,mm from the wire. Using it instead of the SurgicAI
grasp point on the arc raises the cross-validated error from 0.46 to 3.07\,mm at
$\pm30^\circ$ yaw. In addition, the noise floor is correct only when the taught
grasp itself is repeated from a fresh approach. With one grasp per placement the
floor reads 0.31\,mm, while the achieved error is 0.64\,mm. In a power analysis
with a 1\,mm curved bias, 45 placements detected curvature in 6/6 seeds and
produced no false positives at any sample size. We therefore plan 60 placements.

\begin{figure*}[t]
  \centering
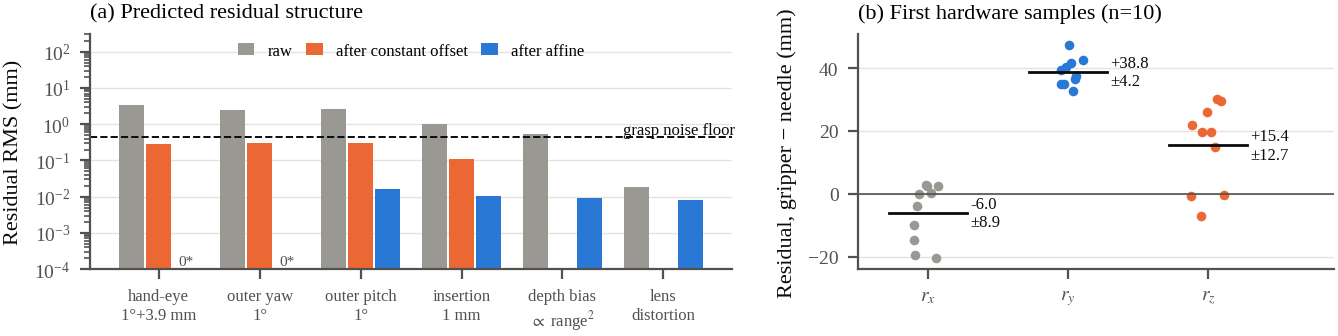
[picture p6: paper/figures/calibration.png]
  
  \caption{(a) Residual RMS over a 4\,cm box predicted from the dVRK kinematics
  for each error source: raw, after removing a constant, and after an affine fit.
  The dashed line is the rehearsed grasp noise floor, and 0* marks terms that are
  exactly affine (${<}10^{-12}$\,mm). (b) Residuals of the first ten hardware
  samples. The near-constant $r_y\approx+39$\,mm (s.d.\ 4.2\,mm, over five days
  and $\sim$150$^\circ$ of wrist variation) points to a frame-definition offset
  rather than to calibration error.}
  \label{fig:calib}
\end{figure*}

\subsection{First hardware samples}
Ten placements have been recorded on our dVRK (Fig.~\ref{fig:calib}b), and none
can yet be used in a fit. \emph{First}, the gripper poses were judged ``ready
to grasp'' by eye, and the jaws were not closed on the needle. The per-axis
correlation between the needle and gripper positions is 0.64, 0.76 and 0.15 for
$x$, $y$ and $z$, the signature of an operator reading depth from a flat
endoscope image. \emph{Second}, the residual contains a constant of about 43\,mm,
mostly in $y$. A constant offset is invisible to a transform-invariant check,
since rigid transforms preserve distances. Our leading hypothesis is a frame
mismatch: \texttt{measured\_cp} is published in an ``ECM'' frame, while the
hand-eye transform maps the camera to the ECM \emph{tip}. Consecutive samples
with the wrist held steady are consistent to within 1.2--1.8\,mm, while samples
taken minutes or days apart are not. The next session will confirm the frame
and collect verified grasps: jaws closed, needle lifted 5--10\,mm, and three
fresh approaches per placement.

%%%%%%%%%%%%%%%%%%%%%%%%%%%%%%%%%%%%%%%%%%%%%%%%%%%%%%%%%%%%%%%%%%%%%%%%%%%%%%%%
\section{DISCUSSION AND LIMITATIONS}

The largest obstacles to transfer were not dynamics or appearance. They were
conventions: an Euler branch, a step size that exists in two versions, whether
the observation closes the loop, a 7\,mm standoff, and the sign of the jaw
angle. Each one looks correct in isolation, and each one fails silently. Our
main methodological recommendation is to measure a deployment contract by
replaying the policy's own demonstrations before running it on a robot, and to
treat any mismatch between replay and the published rate as a bug.

This draft has clear limits. (i) No closed-loop grasp or suture on the real
robot has been completed yet. The hardware results are bring-up findings, dry
runs and calibration samples, and the complete sequence has been validated only
offline. (ii) The hardware RL-versus-servo comparisons made before the contract
fixes are void, and they have not yet been repeated. (iii) The high-level PPO
checkpoint is not available, so the hierarchy results use scripted sequencing,
and $n{=}20$ gives wide intervals. (iv) Place reproduces only 12/25 at a
$10^\circ$ tolerance and does not drive the arm. (v) FoundationPose tracking of
the PSM is not yet reliable (Sec.~\ref{sec:perception}), and the needle-yaw cap
of the pose audit limits the workspace. (vi) Hysteresis is not a function of
position and cannot be represented by any $f(x,y,z)$. Keeping the approach
direction consistent is the only mitigation we apply.

%%%%%%%%%%%%%%%%%%%%%%%%%%%%%%%%%%%%%%%%%%%%%%%%%%%%%%%%%%%%%%%%%%%%%%%%%%%%%%%%
\section{CONCLUSION AND FUTURE WORK}

We replicated the SurgicAI hierarchy on a modern ROS~2 stack and built a
perception front end for the real endoscope. We then made the released policies
executable on a real dVRK PSM through a verified contract, a staging solve and a
guarded phase machine. Next steps, in order: resolve the 43\,mm frame offset and
collect verified grasps; run the empty-gripper rehearsal and then live grasp,
lift and transport with the manual gate; repeat the RL-versus-servo comparison
through the corrected contract; and retrain with start-pose randomization,
which the released Approach demonstrations lack entirely (one distinct start
pose across 50 episodes), and with a Place policy trained to a tight
orientation tolerance.

%%%%%%%%%%%%%%%%%%%%%%%%%%%%%%%%%%%%%%%%%%%%%%%%%%%%%%%%%%%%%%%%%%%%%%%%%%%%%%%%
\section*{APPENDIX}

\textbf{Reproducibility.} The hierarchy replication is on branch
\texttt{jin-hierarchical-repro} of \texttt{xiangruiSun/SurgicAI}
(\texttt{RL/run\_jin\_hierarchical.py}). The deployment, calibration and all
offline tools are in the project repository under \texttt{deploy/}, with the
simulation environments under \texttt{src/SurgicAI/RL/}. The replay numbers
come from \texttt{tools/replay\_demos.py}, the staging analysis from
\texttt{tools/workspace\_spec.py}, the residual structure from
\texttt{tools/residual\_structure.py} and the rehearsals from
\texttt{tools/offline\_grasp\_lift.py}. The script that regenerates every data
figure in this draft is in \texttt{paper/make\_figures.py}.

\textbf{Checkpoint registry.} Upstream Approach TD3+HER+BC
(SHA-256 prefix \texttt{06fc7813f93f}), upstream Place (\texttt{4fc615f07415})
and R6 (\texttt{6286a88c21f0}). All three act at 1.0\,mm\,/\,3$^\circ$.

\section*{ACKNOWLEDGMENT}

We thank the authors of SurgicAI, AMBF and the Surgical Robotics Challenge for
releasing their code and models. \todo{Add lab, hardware and funding
acknowledgments as appropriate.}

\begin{thebibliography}{99}

\bibitem{munawar2019ambf}
A.~Munawar, Y.~Wang, R.~Gondokaryono, and G.~S.~Fischer, ``A real-time dynamic
simulator and an associated front-end representation format for simulating
complex robots and environments,'' in \emph{Proc. IEEE/RSJ IROS}, 2019,
pp.~1875--1882.

\bibitem{munawar2022src}
A.~Munawar, J.~Y.~Wu, G.~S.~Fischer, R.~H.~Taylor, and P.~Kazanzides, ``Open
simulation environment for learning and practice of robot-assisted surgical
suturing,'' \emph{IEEE Robot. Autom. Lett.}, vol.~7, no.~2, pp.~3843--3850, 2022.

\bibitem{wu2024surgicai}
J.~Wu, H.~Zhou, P.~Kazanzides, A.~Munawar, and A.~Liu, ``SurgicAI: A hierarchical
platform for fine-grained surgical policy learning and benchmarking,'' in
\emph{Advances in Neural Information Processing Systems (Datasets and Benchmarks
Track)}, 2024.

\bibitem{yu2024orbit}
Q.~Yu \emph{et~al.}, ``Orbit-Surgical: An open-simulation framework for learning
surgical augmented dexterity,'' in \emph{Proc. IEEE ICRA}, 2024.

\bibitem{review2026rl}
``Applications of reinforcement learning for autonomous surgical robotics: A
systematic review,'' 2026, PMC13511724. \todo{complete citation}

\bibitem{kazanzides2014dvrk}
P.~Kazanzides, Z.~Chen, A.~Deguet, G.~S.~Fischer, R.~H.~Taylor, and
S.~P.~DiMaio, ``An open-source research kit for the da Vinci surgical system,''
in \emph{Proc. IEEE ICRA}, 2014, pp.~6434--6439.

\bibitem{fujimoto2018td3}
S.~Fujimoto, H.~van~Hoof, and D.~Meger, ``Addressing function approximation
error in actor-critic methods,'' in \emph{Proc. ICML}, 2018.

\bibitem{andrychowicz2017her}
M.~Andrychowicz \emph{et~al.}, ``Hindsight experience replay,'' in
\emph{Advances in Neural Information Processing Systems}, 2017.

\bibitem{xie2022randomization}
Z.~Xie \emph{et~al.}, ``Analysis of randomization effects on sim2real transfer in
reinforcement learning for robotic manipulation tasks,'' arXiv:2206.06282, 2022.

\bibitem{chiu2022needle}
Z.-Y.~Chiu, A.~Z.~Liao, F.~Richter, B.~Johnson, and M.~C.~Yip, ``Markerless
suture needle 6D pose tracking with robust uncertainty estimation for autonomous
minimally invasive robotic surgery,'' in \emph{Proc. IEEE/RSJ IROS}, 2022.

\bibitem{wen2024foundationpose}
B.~Wen, W.~Yang, J.~Kautz, and S.~Birchfield, ``FoundationPose: Unified 6D pose
estimation and tracking of novel objects,'' in \emph{Proc. IEEE/CVF CVPR}, 2024.

\bibitem{hwang2020calibrating}
M.~Hwang \emph{et~al.}, ``Efficiently calibrating cable-driven surgical robots
with RGBD fiducial sensing and recurrent neural networks,'' \emph{IEEE Robot.
Autom. Lett.}, vol.~5, no.~4, pp.~5937--5944, 2020.

\bibitem{xiao2022delta}
B.~Xiao, A.~Alamdar, K.~Song, A.~Ebrahimi, P.~Gehlbach, R.~H.~Taylor, and
I.~Iordachita, ``Delta robot kinematic calibration for precise robot-assisted
retinal surgery,'' in \emph{Proc. Int. Symp. Medical Robotics (ISMR)}, 2022.

\bibitem{yang2024depthv2}
L.~Yang, B.~Kang, Z.~Huang, Z.~Zhao, X.~Xu, J.~Feng, and H.~Zhao, ``Depth
Anything V2,'' in \emph{Advances in Neural Information Processing Systems}, 2024.

\bibitem{garrido2014aruco}
S.~Garrido-Jurado, R.~Mu\~noz-Salinas, F.~J.~Madrid-Cuevas, and
M.~J.~Mar\'in-Jim\'enez, ``Automatic generation and detection of highly reliable
fiducial markers under occlusion,'' \emph{Pattern Recognition}, vol.~47, no.~6,
pp.~2280--2292, 2014.

\end{thebibliography}

\end{document}

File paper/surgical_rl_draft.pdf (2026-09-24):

DRAFT – prepared for publication, not yet peer reviewed – September 24, 2026

## Autonomous Suturing Task: From Hierarchical Policies in Simulation to a Guarded Needle-Handling Pipeline on a Real dVRK

Xiangrui Sun¹,∗

, Jiaming Wen²,∗

, Adnan Munawar¹,†

, and Anqi Liu³,†

Abstract— Reinforcement-learning (RL) policies for surgical suturing are commonly trained and scored in simulation and seldom run on a physical robot. We report our progress in moving the hierarchical suturing policies of SurgicAI onto a da Vinci Research Kit (dVRK). First, we re-run the original five-stage hierarchy (Approach, Place, Insert, Regrasp, Pullout) on ROS 2 and AMBF 3 without changing any policy or environment logic. It completes the full suture in 11 of 20 episodes, against the 52% reported by its authors. Second, we build a perception front end for the real endoscope. Depth Anything V2 is fine-tuned on simulated RGB–depth pairs so that it outputs metric depth, and FoundationPose uses that depth to estimate the pose of the needle. An ArUco-based hand-eye calibration improves PSM localization from about

### 5 cm to 5–10 mm. Third, we deploy the released policies on

a real PSM through an explicit observation–action contract. Running the policies against their own demonstrations exposed three silent mismatches between the training environment and a straightforward deployment: the Euler-angle branch, the action scale, and whether the observation is open- or closed-loop. Once these are fixed, the released Approach checkpoint reproduces 45 of its 50 demonstrations. We also show that the gap between the training workspace and the real task can be closed by staging the start pose rather than by retraining, and we describe a guarded phase machine that takes the arm from staging through grasp, lift and transport to the suture entry pose. Finally, we propose a two-stage grasp calibration, in which a Bernstein residual field corrects a coarse FoundationPose-based grasp target, and report the first ten hardware samples. They reveal a constant offset of about 43 mm that must be removed before any fit.

I. INTRODUCTION

Suturing is the canonical benchmark for surgical autonomy. It is long-horizon, contact-rich, and needs millimetre precision on a thin, curved, near-symmetric object. Simulation platforms built on AMBF [1] and the Surgical Robotics Challenge (SRC) [2] have made the task learnable. SurgicAI [3] splits it into five subtasks and learns a policy for each one. A high-level policy then sequences them, and the full

This work was not supported by any organization.
∗Xiangrui Sun and Jiaming Wen contributed equally to this work (co-first authors).
Draft manuscript prepared for publication. Results, figures and text are preliminary and subject to change.
†Corresponding authors: Adnan Munawar amunawa2@jhu.edu; Anqi Liu aliu.cs@jhu.edu.
1Xiangrui Sun and Adnan Munawar are with the Laboratory for Computational Sensing and Robotics, Johns Hopkins University, Baltimore, MD 21218, USA xsun97@jh.edu
2
Jiaming Wen is with [affiliation] [email]
3Anqi Liu is with the Department of Computer Science, Johns Hopkins University, Baltimore, MD 21218, USA

chain succeeds far more often with this hierarchy than with a flat policy. Physical deployments remain rare. Orbit-Surgical transferred a policy to a real dVRK at 50% on needle lift [4], and a recent review describes the field as “mature at the simulation stage but . . . preclinical” [5].
This draft reports what it has taken so far to move the SurgicAI policies onto a real dVRK [6] Patient Side Manipulator (PSM). We emphasize where the transfer actually broke. Much of the gap turned out not to be “sim-to-real” in the usual sense. The cause was usually an unstated convention in the training code that a deployment has to reproduce exactly. Our contributions are:
1) A replication of the hierarchical suturing pipeline on ROS 2/AMBF 3. The environment and policy code are unchanged, and the chained success rates are consistent with the published ones (Sec. III).
2) A perception front end for the real endoscope: simsupervised metric depth, FoundationPose needle tracking and hand-eye registration of the PSM (Sec. IV).
3) A verified deployment contract for the released checkpoints. It identifies three defects that invalidate a straightforward deployment, and a staging solve that places any real grasp inside the trained support (Sec. V).
4) A guarded real-robot phase machine and the hardware findings from bringing it up, including the PSM position deadband (Sec. VI).
5) A two-stage grasp calibration whose structure is predicted from the dVRK kinematics before any data is collected, together with the first hardware samples (Sec. VII).
Fig. 1 shows how the components fit together.

II. RELATED WORK
Learning suturing in simulation. AMBF [1] and the SRC [2] provide a dVRK-faithful suturing scene with a needle, a phantom and entry/exit targets. SurgicAI [3] benchmarks RL and imitation-learning algorithms on its subtasks. TD3 [7] with hindsight experience replay [8] and a behaviorcloning term reaches roughly 96% on single subtasks. The hierarchical composition reaches 52% on the full chain, compared with 15% for a flat policy. Orbit-Surgical [4] trains in GPU-parallel simulation and reports a physical transfer. Sim-to-real. Domain randomization is the principal mitigation. Xie et al. [9] find that randomizing one dimension at a time transfers more reliably than randomizing everything

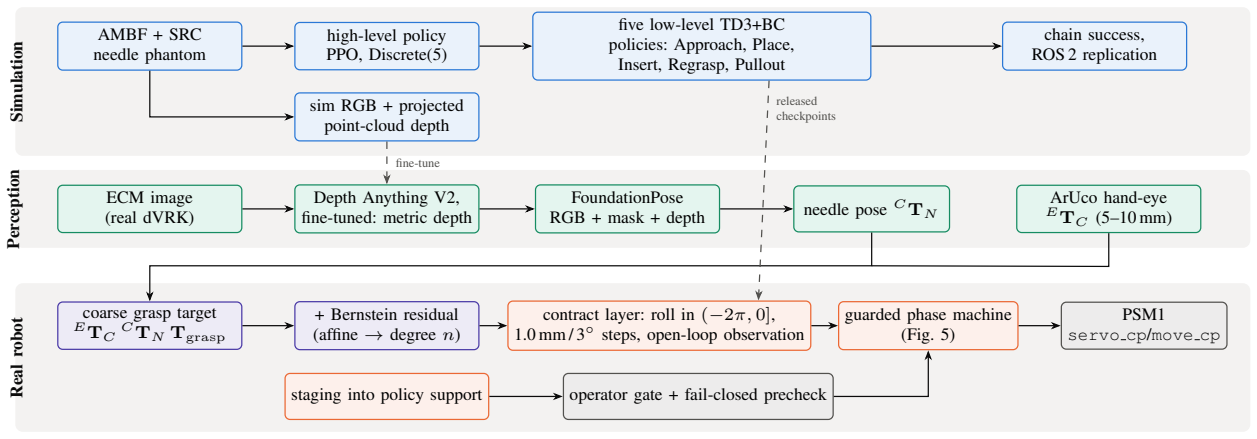
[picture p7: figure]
Simulation Perception Real robot; AMBF + SRC needle phantom; high-level policy PPO, Discrete(5); five low-level TD3+BC policies: Approach, Place, Insert, Regrasp, Pullout; chain success, ROS 2 replication; sim RGB + projected point-cloud depth; ECM image (real dVRK); Depth Anything V2, fine-tuned: metric depth; FoundationPose; RGB + mask + depth; needle pose C TN; ArUco hand-eye ETC (5–10 mm); fine-tune; coarse grasp target ETC; C TN Tgrasp; + Bernstein residual (affine → degree n); contract layer: roll in (−2π, 0], 1.0 mm / 3◦; steps, open-loop observation; guarded phase machine (Fig. 5)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

Fig. 1. System overview. Simulation: the SurgicAI hierarchy in AMBF/SRC, re-run on ROS 2; the same simulator provides RGB–depth pairs for depth fine-tuning. Perception: on the real dVRK, fine-tuned Depth Anything V2 supplies metric depth to FoundationPose, and an ArUco hand-eye calibration registers the camera to the PSM. Real robot: the perceived needle pose becomes a coarse grasp target, which a learned residual corrects. The released checkpoints drive the arm only through a verified contract layer and a guarded phase machine.

TABLE I

STAGES OF THE HIERARCHY, AS USED BY THE LOW-LEVEL

CONTROLLER.

Task Stage | Arm | Completion side effect
1 | Approach PSM2 close jaw, attach needle
2 | Place | PSM2 re-sync goal from measured pose
3 | Insert | PSM2 –
4 | Regrasp | PSM1 PSM1 grasps, PSM2 opens
5 | Pullout | PSM1 episode terminates with success

at once. We adopt their stopping rule for a retraining curriculum, but our results suggest that the first-order transfer problems for these policies are contract mismatches rather than visual or dynamic gaps.
Needle pose and robot calibration. Markerless needle pose tracking reaches roughly 1 mm [10]. Foundation-Pose [11] provides model-based 6D pose from RGB-D with no object-specific training. Kinematic error on the dVRK is dominated by joint offsets and cable effects [12]. Hwang et al. need a recurrent model because hysteresis is not a function of position. We build on the two-stage calibration of Xiao et al. [13], a coarse geometric model followed by a Bernstein-polynomial residual.

III. HIERARCHICAL SUTURING IN SIMULATION

A. The SurgicAI hierarchy

The hierarchy has a high-level PPO policy with a 35-dimensional observation and five discrete actions. Each action selects a low-level TD3+BC policy (Table I), and each low-level policy runs for at most 200 steps. Every low-level policy is goal-conditioned on a 7-DoF target made of position, roll–pitch–yaw and jaw. It outputs a normalized increment that is scaled by a per-task step size and integrated into the commanded pose.

B. Porting to ROS 2 and AMBF 3
The original code targets ROS 1 Noetic, AMBF 2.0 and a 2024 snapshot of the SRC. We run it unchanged on Ubuntu 24.04 with ROS 2 Jazzy by adding three pieces. The first is a minimal rospy shim built on the ROS abstraction layer that the ROS 2 AMBF client already uses. The second is a set of repository-relative model and config paths. The third is a set of runtime fixes for three problems in the ROS 2 AMBF client that only the old scene exposes: sensors that do not accept the middleware handle, incremental DDS discovery that silently misses objects, and name lookups made ambiguous by ghost objects. Checkpoints saved under Python 3.8 load under Python 3.12 with Stable-Baselines3 2.2.1 and give identical predictions once trainingonly pickles are skipped.
C. Results
The high-level PPO checkpoint has not been released. We therefore sequence the five stages in order and allow up to two retries per stage. This stands in for a high-level policy that keeps selecting a stage until it completes. The low-level checkpoints are recovered from the repository history. Fig. 2 compares 20 episodes (seed 10) with Table 3 of [3] (100 episodes; “Regrasp” is called “Handoff” there). The full chain succeeds in 11/20 episodes (0.55), against 0.52 in the paper. All nine failures reach the 800-step low-level limit: seven in Pullout and two in Place. The mean number of steps per completed stage is 139 for Approach, 59 for Place, 88 for Insert, 154 for Regrasp and 111 for Pullout. We also found a bookkeeping bug. info["is success"] is set when Pullout completes but is overwritten later in the same function, so it is never true. Success is therefore counted from terminated, which is also what the high-level reward uses.
The intermediate chains exceed the published values (0.90 against 0.72 and 0.60). The likeliest reason is our stage sequencing: it always retries rather than letting a learned

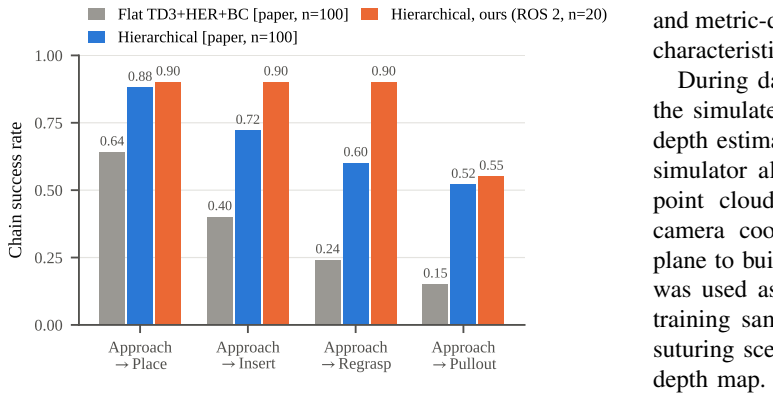
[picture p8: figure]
Approach Place; Approach Insert; Approach Regrasp; Approach Pullout; Chain success rate; Flat TD3+HER+BC [paper, n=100]; Hierarchical [paper, n=100]; Hierarchical, ours (ROS 2, n=20); depth map.

Fig. 2. Chained success from Approach to each later stage. Grey and blue: flat and hierarchical results from [3] (n=100); the flat TD3+HER baseline, 0.00 throughout, is omitted. Orange: our replication on ROS 2/AMBF 3 (n=20), with scripted stage sequencing in place of the unreleased high-level policy. With n=20 the 95% interval on 0.55 is about ±0.22.

TABLE II

WHAT THE POLICIES ASSUME, OLD VS. CURRENT SRC (STATIC CHECK).

Assumption | Old SRC (policies) | SRC v2.x
middleware | ROS 1 | ROS 2
needle topic | env/Needle | env/phantom/Needle
FK module | psmFK | removed
PSM1 base | (1.0, 1.346, 1.350),
| 0.1-scaled | (0.131, 0.397, 0.878) m
needle spawn | hard-coded world pose differs per phantom

high-level policy choose, and a retry can recover a stage that a policy would have abandoned. Table II shows why the policies cannot run on the newer SRC scenes without adaptation. The observations are absolute poses in the PSM base frame, and the base-to-needle offset changes by several centimetres between the old and new worlds.

IV. PERCEPTION ON THE REAL DVRK

A. Simulation-Based Adaptation of Depth Anything for Metric Depth Estimation
We first evaluated the pretrained Depth Anything V2 model [14] on images from the simulated suturing environment without task-specific fine-tuning. In this baseline configuration the model produced relative depth estimates, normalized to a range of approximately 0 to 1, rather than physically meaningful metric depth. The pretrained model had also never seen the visual characteristics of the surgical scene: the surgical instruments, the tissue phantom and the endoscopic imaging conditions. Its depth predictions therefore had substantial errors and were not accurate enough for downstream robotic perception and manipulation.
To adapt the model to the surgical domain and make it predict absolute depth in meters, we fine-tuned it on data generated from the AMBF-based suturing simulation environment. Collecting equivalent supervised training data directly from the physical dVRK is difficult because the real endoscopic camera provides no dense ground-truth depth. The simulator is therefore an effective source of paired RGB and metric-depth data that preserves the visual and geometric characteristics of the target surgical scenario.
During data collection, RGB images were acquired from the simulated endoscopic camera and used as inputs to the depth estimation network. For each RGB frame, the AMBF simulator also provided a corresponding three-dimensional point cloud. The 3-D points were transformed into the camera coordinate system and projected onto the image plane to build a dense per-pixel depth map in meters, which was used as ground-truth supervision for fine-tuning. Each training sample was thus an RGB image of the simulated suturing scene paired with its geometrically derived metric-

After task-specific fine-tuning, the model estimated depth substantially better within the suturing environment. Instead of relative depth, the adapted model predicts depth directly in metric units and reproduces the spatial structure of the surgical scene more accurately. This simulation-based training strategy is a practical way to obtain dense depth supervision that is difficult to acquire on the physical dVRK, and it adapts the pretrained depth estimator to the geometric and visual characteristics of robot-assisted suturing. [Jiaming: add the quantitative depth error before and after fine-tuning (e.g. AbsRel, RMSE in mm) and the size of the training set.]

B. FoundationPose Tracking on the Real dVRK System [unfinished – Jiaming: add experimental results and explain the observed tracking failure.] FoundationPose [11] was used to estimate the poses of the PSM and the surgical needle on the physical dVRK. The method requires an RGB image, an object mask and a depth map as inputs. Because the dVRK endoscope provides no direct depth measurements, the depth maps were generated with the fine-tuned Depth Anything model.
The pipeline tracked the surgical needle reliably. Tracking of the PSM was less stable and had larger pose errors. When tracking the PSM [. . . ]
In simulation, the complete path from RGB through Depth Anything, FoundationPose and a first-frame physicalplausibility gate to a frozen needle goal passed the gate on 40/40 captures. A Reach controller driven by these goals succeeded in 29/30 episodes. [Confirm which goal source (GT vs. FP) the 29/30 refers to; these are historical reference runs and were not re-run for this draft.] Needle yaw in the curriculum is capped at ±30◦ because the pose audit was reliable at 20◦ but produced near-180◦ flips at 40◦
. Section V-C shows that this cap, not the policy’s trained workspace, is what limits the task.
C. Hand-Eye Calibration for PSM Localization
To obtain an independent estimate of the PSM pose in the camera frame, we performed hand-eye calibration with the dVRK camera registration framework. An ArUco marker [15] was mounted on the PSM shaft approximately 70 mm from the instrument tip. The camera was positioned so that the marker stayed near the center of the image, and the PSM was moved through multiple poses while the marker remained visible. The recorded robot and marker poses were then used to estimate the transformation between the PSM and camera frames.
This calibration improves the PSM localization accuracy from approximately 5 cm to 5–10 mm. The resulting pose estimate is an additional reference that can be fused with the FoundationPose estimate, for example with a Kalman filter, to make PSM tracking more robust. Section VII explains why hand-eye error of this size is exactly affine in position and can therefore be absorbed by the grasp calibration.
V. DEPLOYING THE RELEASED POLICIES

We deploy three checkpoints: the released SurgicAI Approach and Place policies (TD3+HER+BC) and R6, a locally retrained single-goal Approach policy. Deployment is inference-only. It uses a CPU-loaded 3×256 actor and the arm’s measured cp in the ECM frame. It does not use AMBF or any training code.

A. The observation–action contract
The contract is decoded from the checkpoints themselves. Observation: o = [a, d, d−a] ∈ R

21, where a and d
are the achieved and desired poses. Each is written as position in centimetres, RPY in radians (extrinsic xyz, KDL GetRPY), and jaw normalized to [0, 1]. Our observation builder reproduces all 502 observations stored in the R6 checkpoint exactly.
Action: u ∈ [−1, 1]⁷
is integrated as ct+1 = ct + u ⊙ s. The step s is in metres and radians while the observation is in centimetres, and this asymmetry is part of the contract.
B. Three silent defects
A deployment can satisfy all of the above and still fail. We replayed each checkpoint from its own demonstration starts against a kinematic arm model, and this found three further defects. Together they invalidate every hardware RL comparison we had made before fixing them.
1) The roll branch. A rotation matrix is branch-invariant, but its RPY triple is not. SciPy returns roll in [−π, π], whereas SurgicAI’s Frame2Vec maps it into (−2π, 0]. All stored goal rolls in the released checkpoints lie outside ±π, and none lies outside (−2π, 0]. With the SciPy convention, upstream Approach reproduces 0/25 demonstrations. The geometric servo was never affected because it uses only relative rotation. This is why “the servo works and RL does not” looked like a statement about policy quality for so long.
2) Two action scales. The environment metadata stores 0.5 mm / 2◦
, the scale the demonstrations integrate at, and fitting the demonstrations recovers this value exactly. The training and evaluation scripts, however, hard-code 1.0 mm / 3◦ ,
and all published success rates were measured at that scale. Replay picks 1.0 mm / 3◦ unambiguously (Fig. 3a). The 1.5 mm we had been applying came from a utility module and was never checked against the policy.
3) Open- vs. closed-loop observation. Inside a subtask, SurgicAI feeds the network the integrated command, never the measured pose. A perfect arm hides the difference. For a lagging arm, feeding the measured pose drops Approach from 25/25 to 6/25 at 30% tracking per cycle (Fig. 3b). We now compute the observation from an internal integrator seeded once, and the measured pose is used only by the guards. A fourth defect appeared while testing this fix. The per-step safety caps were measured against the measured pose, so they pulled the command back toward a lagging arm on every cycle. This re-closed the loop from inside the safety layer. The caps now bound consecutive commands, and a separate guard bounds tracking error.
With all three defects fixed, upstream Approach reproduces 45/50 of its demonstrations through our loop (published 96 ± 6%), and R6 reproduces 46/50. We also found that the published rates use a tolerance of 0.5 cm / 30◦
. At that
tolerance Approach reproduces 25/25 and Place 22/25. At 10◦
, the tolerance in the environment metadata, Place drops to 12/25, so Place is not a precision orientation controller.
C. The workspace question is a staging question

On the real task, the released Approach policy is out of distribution. The needed start-to-goal rotation is 0–30◦
, while
training covered 53–97◦
, and the tool-frame offset has the wrong sign in y. Every unstaged RL run orbited the goal. We first expected this to require retraining on a wider workspace. However, the demonstrated support of a goal-conditioned policy is expressed entirely in relative quantities:

δ = R

⊤
s
(pg − ps), | θ = ∠(Rs, Rg), | (1)

and both are invariant to rigid transforms. For any grasp pose (pg, Rg) there is therefore a start pose inside the support, and it can be solved for directly:

Rs = Rg Rel⁻¹
| | , | ps = pg − Rs δ

⋆
| | | | , | (2)

where Rel and δ

| ⋆
are the rotation and offset taken from the support. We evaluate this on the recorded geometry of our dVRK with 400 needle placements over a ±3 mm, ±30◦ envelope. Without staging, 0/400 placements are in support. With staging, all 400 are, and the staging move has a median length of 3.66 cm and a maximum of 4.14 cm (Fig. 4). For the approach leg, the trained workspace is not the binding constraint. The binding constraints are perception (the ±30◦ yaw cap), reachability and Place.
D. The trained goal is 7 mm short of the needle
SurgicAI | builds | the | Approach | goal | as
TN (ϕ) Trans(0, 0, 7 mm) Rflip. It is the grasp point on the arc, backed off 7 mm along the tool axis with the jaws pointing at it. In simulation the grasp is then faked by attaching the needle wherever the jaws are, so no trained motion ever covers the last 7 mm. On hardware, closing the jaw at the policy goal would close on empty space. We therefore add a descend phase that covers the standoff at 0.5 mm per cycle along the jaw axis with the orientation frozen. It is the slowest motion in the sequence because it is the only one that can disturb the needle before the needle is held.

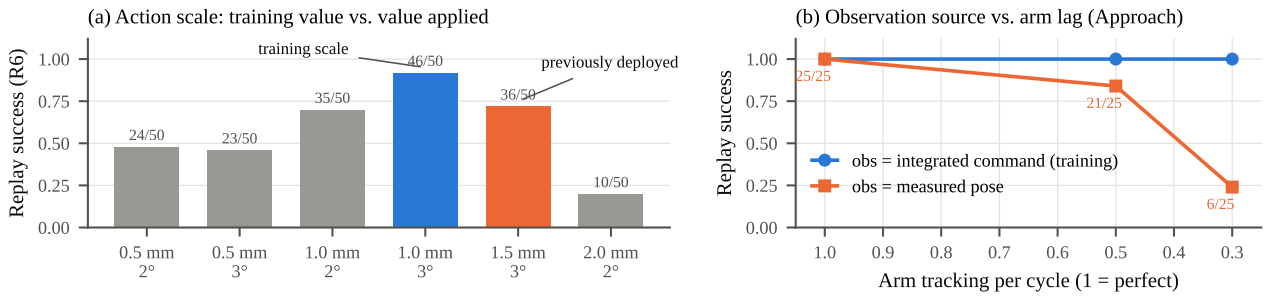
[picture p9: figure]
Replay success (R6); training scale; previously deployed; Arm tracking per cycle (1 = perfect); Replay success; obs = integrated command (training); obs = measured pose

(a) Action scale: training value vs. value applied
(b) Observation source vs. arm lag (Approach)

Fig. 3. Two contract defects, measured by replaying policies from their own demonstration starts. (a) R6 success as a function of action scale at its own tolerance (1 cm / 10◦, 200 steps): the training scale gives 46/50, and the scale previously deployed gives 36/50. (b) Upstream Approach under a first-order lagging arm. Feeding the measured pose instead of the integrated command matches the training environment only for a perfect arm.

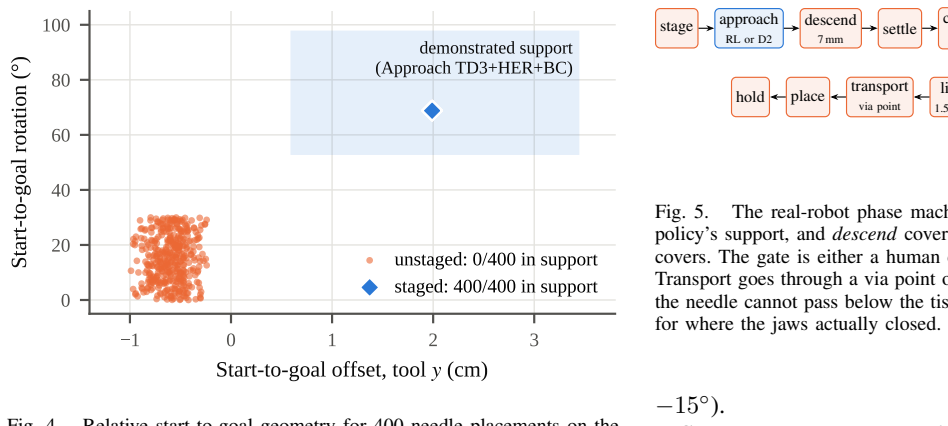
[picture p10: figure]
Start-to-goal offset, tool y (cm); Start-to-goal rotation (°); demonstrated support (Approach TD3+HER+BC); unstaged: 0/400 in support; staged: 400/400 in support; stage; approach; via point hold; place; for where the jaws actually closed.

Fig. 4. Relative start-to-goal geometry for 400 needle placements on the recorded dVRK task, against the demonstrated support of the upstream Approach policy. Staging moves every placement to the same point inside the support. It is a 3.7 cm median move, well inside the 8 cm path-radius
guard. Computed with deploy/tools/workspace spec.py.

VI. A GUARDED NEEDLE-HANDLING SEQUENCE

A. Phase machine

Fig. 5 shows the sequence. The task is specified by three tool poses in the frame of measured cp: the start pose, read from the arm; the grasp pose; and the suture pose, at which the needle sits angled at the entry point. Needle-frame targets cannot be used, because after a blind grasp the needlein-jaw transform is unknown. The approach leg may use the RL policy or a staged SE(3) servo (D2). Transport uses the servo. The Place policy runs in shadow mode only: on the recorded geometry it reports itself out of distribution as soon as transport begins, which is consistent with its replay results above.
No grasp sensor. The simulator attaches the needle by fiat, and hardware has no equivalent. Grasp evidence comes from two indirect channels: the jaw-angle residual relative to an empty-jaw baseline, and jaw effort, which not every arm publishes. Both are logged with grasp verified=false. The default gate is manual. Jaw units are a further sim-toreal trap: on the dVRK negative jaw angles mean squeeze, so mapping “closed” to 0 applies no tendon tension at all. The grip is therefore commanded on a separate channel (default

descend

7 mm

settle close jaw
observe

gate lift

1.5 cm

transport

abort: hold last
command, jaw
never opened

on refusal, slip, stale pose, tracking lag or step budget, from any phase

Fig. 5. The real-robot phase machine. Staging places the arm inside the policy’s support, and descend covers the 7 mm standoff that training never covers. The gate is either a human confirmation (default) or jaw evidence. Transport goes through a via point one lift height above the suture pose, so the needle cannot pass below the tissue plane. The suture pose is corrected

Suture-pose compensation. A suture pose taught by jogging the arm while it holds the needle encodes how the needle sat in the jaws at that moment. Let W be the needle pose, E its required pose and G the grasp. The tool must reach S = E W⁻¹G. A pose St taught with grasp Gt therefore transfers to an actual grasp Ga as

Sa = St G

−1
t | Ga, | (3)

in which neither E nor W appears. Corrections larger than 10 mm abort, because a correction that large most likely means the needle moved.
Safety envelope. A fail-closed precheck verifies reachability, the workspace and operator boxes, step budgets, and tolerances against the lift distance and the deadband. The operator must state the lift sign, because +z in the ECM frame is not guaranteed to point away from the tissue. Runtime guards cap each command at 2.5 mm and 5◦
| | , abort
on 1.5 cm of tracking lag or on a measured cp older than 0.25 s, and never open the jaw on abort.
B. Hardware bring-up findings
Position deadband. During the first live staging move, the arm stayed at 0.25 cm error for 49 cycles without moving at all. A single hand-published 2 mm setpoint moved it 1.947 mm. The loop, however, was publishing about 0.4 mm per cycle, because a proportional servo shrinks its step near the goal, and the arm ignored these commands. No existing guard detected this, since the command never ran more than 0.4 mm ahead of the arm. We added a minimum command

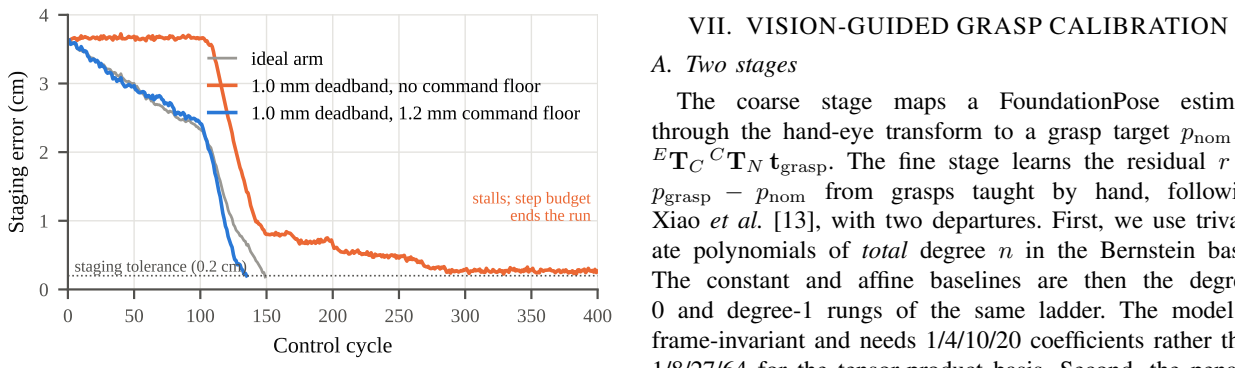
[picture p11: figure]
Control cycle; Staging error (cm); staging tolerance (0.2 cm); stalls; step budget ends the run; 1.0 mm deadband, 1.2 mm command floor; VII. VISION-GUIDED GRASP CALIBRATION; A. Two stages; ETC

| ideal arm 1.0 mm deadband, no command floor
Fig. 6. | Staging under a 1 mm position deadband (offline, arm lag 0.5,
0.2 mm pose noise). Without a command floor, the servo’s shrinking steps are absorbed and the move stalls, as on the hardware, until the step budget ends the run. A 1.2 mm floor restores convergence, and the full nine-phase sequence completes 0.18 cm from the suture pose.

TABLE III

OFFLINE REHEARSAL OF THE FULL SEQUENCE ON THE RECORDED TASK

(D2 APPROACH, 7 MM STANDOFF, 0.2 MM NOISE, SEED 1).

Arm lag per cycle | 0.0 | 0.5 | 0.7
Cycles to completion | 166 | 241 | 337
Final error to suture pose (cm) | 0.064 | 0.076 | 0.098
Precheck | pass | pass | pass

magnitude that stretches a non-zero command up to the measured deadband, along the same direction and never past the target. The precheck now rejects any tolerance finer than the deadband. Fig. 6 reproduces the stall with a deadband model and shows the fix.
Middleware. State topics on the dVRK do not all use the same QoS. A RELIABLE subscriber matched
measured cp but not jaw/measured js, so the jaw ap-
peared absent even though ros2 topic echo showed it publishing. All subscriptions now default to BEST EFFORT. The node also refuses to execute when nothing is subscribed to its command topic, because publishing into the void looks identical to an arm that does not move.
Operator interface. On the first dry run, the gate prompt printed once and then scrolled away under a 10 Hz status line, so the paused arm looked hung. The prompt now repeats and status output is throttled while waiting. A keywordsubstitution error that reached the node’s untested main() led to static checks. Every keyword and every parsed argument is now checked against the real signatures using the Python AST. The deployment package has 588 unit tests, none of which require ROS, a robot or a checkpoint.
C. Offline rehearsal of the full sequence

Every change is rehearsed against a kinematic arm model with first-order lag, pose noise, a jaw model and an optional deadband, using the recorded operator poses. Table III and Fig. 7 show the full sequence with the D2 approach controller and the 7 mm standoff.

The coarse stage maps a FoundationPose estimate through the hand-eye transform to a grasp target pnom = C TN tgrasp. The fine stage learns the residual r = pgrasp − pnom from grasps taught by hand, following Xiao et al. [13], with two departures. First, we use trivariate polynomials of total degree n in the Bernstein basis. The constant and affine baselines are then the degree-0 and degree-1 rungs of the same ladder. The model is frame-invariant and needs 1/4/10/20 coefficients rather than 1/8/27/64 for the tensor-product basis. Second, the penalty is the exact thin-plate curvature energy, whose null space is the affine functions. As λ → ∞ the fit therefore becomes the affine model, and choosing λ by leave-one-placementout cross-validation decides whether curvature has earned its place. The fit is linear and is solved with one QR factorization. The convex-hull property bounds the correction anywhere in the calibrated box, and the runtime refuses to extrapolate outside it.

B. Predicted residual structure
Before collecting any data, we propagate each error source through the dVRK DH parameters over a 4 cm grasping box (Fig. 8a). Hand-eye error is exactly affine: r = (RtrueR⊤
| nom−
I)pnom + b. Offsets in the first two PSM joints rotate the whole distal chain about axes through the base, so they are also affine. Every other geometric term leaves less than 0.02 mm after an affine fit, about twenty times below the repeatability of a taught grasp. A positive result at degree ≥ 2 would therefore be a statement about FoundationPose’s learned bias, not about the robot. Two choices matter more than the degree. The needle mesh origin is the centre of the arc, 10.18 mm from the wire. Using it instead of the SurgicAI grasp point on the arc raises the cross-validated error from 0.46 to 3.07 mm at ±30◦ yaw. In addition, the noise floor is correct only when the taught grasp itself is repeated from a fresh approach. With one grasp per placement the floor reads 0.31 mm, while the achieved error is 0.64 mm. In a power analysis with a 1 mm curved bias, 45 placements detected curvature in 6/6 seeds and produced no false positives at any sample size. We therefore plan 60 placements.
C. First hardware samples
Ten placements have been recorded on our dVRK (Fig. 8b), and none can yet be used in a fit. First, the gripper poses were judged “ready to grasp” by eye, and the jaws were not closed on the needle. The per-axis correlation between the needle and gripper positions is 0.64, 0.76 and 0.15 for x, y and z, the signature of an operator reading depth from a flat endoscope image. Second, the residual contains a constant of about 43 mm, mostly in y. A constant offset is invisible to a transform-invariant check, since rigid transforms preserve distances. Our leading hypothesis is a frame mismatch: measured cp is published in an “ECM” frame, while the hand-eye transform maps the camera to the ECM tip. Consecutive samples with the wrist held steady

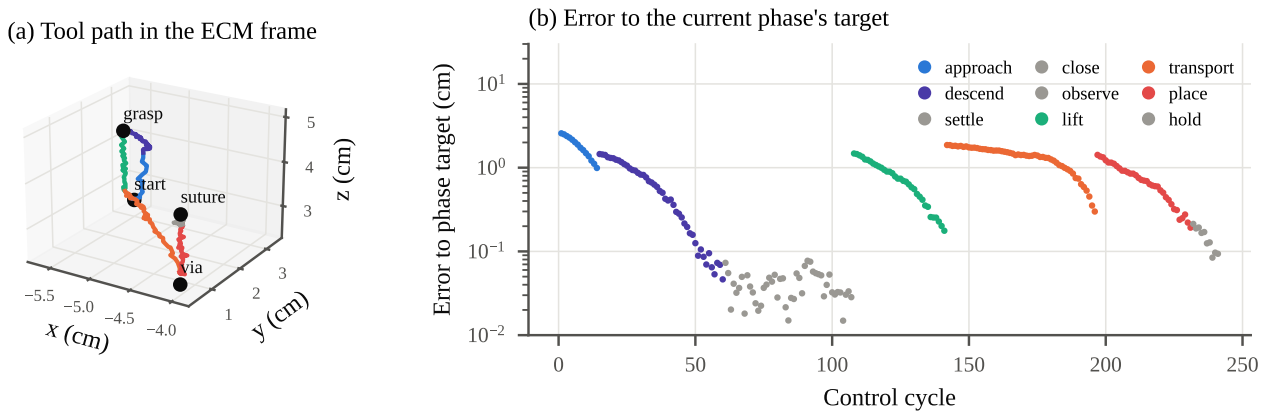
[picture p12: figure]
start; grasp; via; suture; (a) Tool path in the ECM frame; Control cycle; Error to phase target (cm); (b) Error to the current phase's target; approach descend settle; close observe lift; transport place hold

Fig. 7. One rehearsal of the full sequence (arm lag 0.5). (a) Measured tool path in the ECM frame, colored by phase. (b) Error to each phase’s own target. Every motion phase converges before the next begins, and the jaw phases (grey) hold position while the gate is evaluated.

hand-eye
1°+3.9 mm

outer yaw
1°

outer pitch
1°

insertion
1 mm

depth bias
range

2

lens
distortion

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
Residual RMS (mm)

grasp noise floor

0* | 0*
(a) Predicted residual structure
raw | after constant offset | after affine

rx

ry | rz

20

0

20

40

Residual, gripper needle (mm)

-6.0
±8.9

+38.8
±4.2

+15.4
±12.7
(b) First hardware samples (n=10)

Fig. 8. (a) Residual RMS over a 4 cm box predicted from the dVRK kinematics for each error source: raw, after removing a constant, and after an affine fit. The dashed line is the rehearsed grasp noise floor, and 0* marks terms that are exactly affine (<10⁻¹² mm). (b) Residuals of the first ten hardware samples. The near-constant ry ≈ +39 mm (s.d. 4.2 mm, over five days and ∼150◦ of wrist variation) points to a frame-definition offset rather than to calibration error.

are consistent to within 1.2–1.8 mm, while samples taken
minutes or days apart are not. The next session will confirm the frame and collect verified grasps: jaws closed, needle lifted 5–10 mm, and three fresh approaches per placement.

VIII. DISCUSSION AND LIMITATIONS
The largest obstacles to transfer were not dynamics or appearance. They were conventions: an Euler branch, a step size that exists in two versions, whether the observation closes the loop, a 7 mm standoff, and the sign of the jaw angle. Each one looks correct in isolation, and each one fails silently. Our main methodological recommendation is to measure a deployment contract by replaying the policy’s own demonstrations before running it on a robot, and to treat any mismatch between replay and the published rate as a bug. This draft has clear limits. (i) No closed-loop grasp or suture on the real robot has been completed yet. The hardware results are bring-up findings, dry runs and calibration samples, and the complete sequence has been validated only offline. (ii) The hardware RL-versus-servo comparisons made before the contract fixes are void, and they have not yet been repeated. (iii) The high-level PPO checkpoint is not available, so the hierarchy results use scripted sequencing, and n=20 gives wide intervals. (iv) Place reproduces only

12/25 at a 10◦
tolerance and does not drive the arm. (v) FoundationPose tracking of the PSM is not yet reliable (Sec. IV), and the needle-yaw cap of the pose audit limits the workspace. (vi) Hysteresis is not a function of position and cannot be represented by any f(x, y, z). Keeping the approach direction consistent is the only mitigation we apply.

IX. CONCLUSION AND FUTURE WORK

We replicated the SurgicAI hierarchy on a modern ROS 2 stack and built a perception front end for the real endoscope. We then made the released policies executable on a real dVRK PSM through a verified contract, a staging solve and a guarded phase machine. Next steps, in order: resolve the 43 mm frame offset and collect verified grasps; run the empty-gripper rehearsal and then live grasp, lift and transport with the manual gate; repeat the RL-versus-servo comparison through the corrected contract; and retrain with start-pose randomization, which the released Approach demonstrations lack entirely (one distinct start pose across 50 episodes), and with a Place policy trained to a tight orientation tolerance.

APPENDIX

Reproducibility. | The | hierarchy | replication
is | on | branch | jin-hierarchical-repro

of | xiangruiSun/SurgicAI
(RL/run jin hierarchical.py). The deployment,
calibration and all offline tools are in the project repository under deploy/, with the simulation environments under src/SurgicAI/RL/. The replay numbers come from tools/replay demos.py, the staging analysis from tools/workspace spec.py, the residual structure
from | tools/residual structure.py | and | the
rehearsals from tools/offline grasp lift.py. The
script that regenerates every data figure in this draft is in
paper/make figures.py.
Checkpoint registry. Upstream Approach TD3+HER+BC
(SHA-256 | prefix | 06fc7813f93f), | upstream | Place
(4fc615f07415) and R6 (6286a88c21f0). All three
act at 1.0 mm / 3◦

ACKNOWLEDGMENT

We thank the authors of SurgicAI, AMBF and the Surgical Robotics Challenge for releasing their code and models. [Add lab, hardware and funding acknowledgments as appropriate.]

| | REFERENCES
[1] A. Munawar, Y. Wang, R. Gondokaryono, and G. S. Fischer, “A realtime dynamic simulator and an associated front-end representation format for simulating complex robots and environments,” in Proc. IEEE/RSJ IROS, 2019, pp. 1875–1882.
[2] A. Munawar, J. Y. Wu, G. S. Fischer, R. H. Taylor, and P. Kazanzides, “Open simulation environment for learning and practice of robot-assisted surgical suturing,” IEEE Robot. Autom. Lett., vol. 7, no. 2, pp. 3843–3850, 2022.
[3] J. Wu, H. Zhou, P. Kazanzides, A. Munawar, and A. Liu, “SurgicAI: A hierarchical platform for fine-grained surgical policy learning and benchmarking,” in Advances in Neural Information Processing Systems (Datasets and Benchmarks Track), 2024.
[4] Q. Yu et al., “Orbit-Surgical: An open-simulation framework for learning surgical augmented dexterity,” in Proc. IEEE ICRA, 2024.
[5] “Applications of reinforcement learning for autonomous surgical robotics: A systematic review,” 2026, PMC13511724. [complete citation]
[6] P. Kazanzides, Z. Chen, A. Deguet, G. S. Fischer, R. H. Taylor, and
S. P. DiMaio, “An open-source research kit for the da Vinci surgical system,” in Proc. IEEE ICRA, 2014, pp. 6434–6439.
[7] S. Fujimoto, H. van Hoof, and D. Meger, “Addressing function approximation error in actor-critic methods,” in Proc. ICML, 2018.
[8] M. Andrychowicz et al., “Hindsight experience replay,” in Advances in Neural Information Processing Systems, 2017.
[9] Z. Xie et al., “Analysis of randomization effects on sim2real transfer in reinforcement learning for robotic manipulation tasks,” arXiv:2206.06282, 2022.
[10] Z.-Y. Chiu, A. Z. Liao, F. Richter, B. Johnson, and M. C. Yip, “Markerless suture needle 6D pose tracking with robust uncertainty estimation for autonomous minimally invasive robotic surgery,” in Proc. IEEE/RSJ IROS, 2022.
[11] B. Wen, W. Yang, J. Kautz, and S. Birchfield, “FoundationPose: Unified 6D pose estimation and tracking of novel objects,” in Proc. IEEE/CVF CVPR, 2024.
[12] M. Hwang et al., “Efficiently calibrating cable-driven surgical robots with RGBD fiducial sensing and recurrent neural networks,” IEEE Robot. Autom. Lett., vol. 5, no. 4, pp. 5937–5944, 2020.
[13] B. Xiao, A. Alamdar, K. Song, A. Ebrahimi, P. Gehlbach, R. H. Taylor, and I. Iordachita, “Delta robot kinematic calibration for precise robot-assisted retinal surgery,” in Proc. Int. Symp. Medical Robotics (ISMR), 2022.
[14] L. Yang, B. Kang, Z. Huang, Z. Zhao, X. Xu, J. Feng, and H. Zhao, “Depth Anything V2,” in Advances in Neural Information Processing Systems, 2024.
[15] S. Garrido-Jurado, R. Munoz-Salinas, F. J. Madrid-Cuevas, and ˜
M. J. Mar´ın-Jimenez, “Automatic generation and detection of highly ´ reliable fiducial markers under occlusion,” Pattern Recognition, vol. 47, no. 6, pp. 2280–2292, 2014.

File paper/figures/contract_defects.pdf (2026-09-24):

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

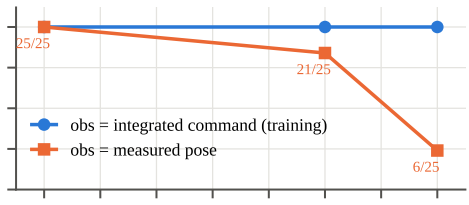
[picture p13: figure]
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

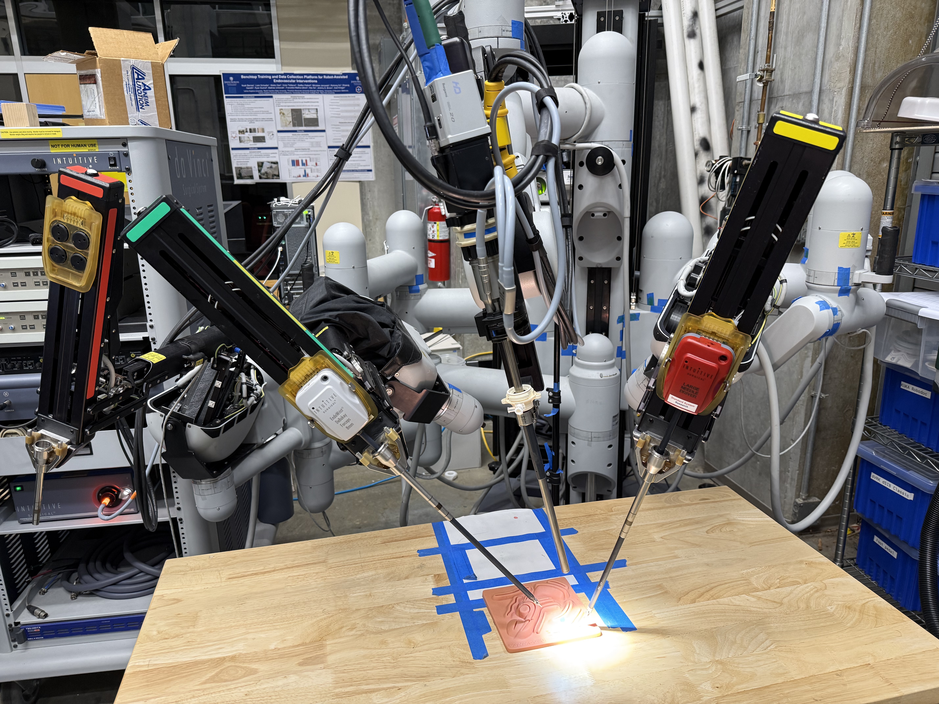
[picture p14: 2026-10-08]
asset/dVRK.jpg

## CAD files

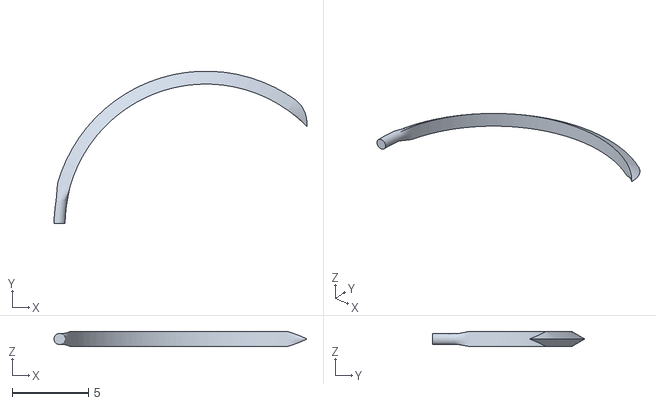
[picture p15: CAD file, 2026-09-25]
asset/Needle_4_exact_mm.stl
16.6 x 9.99 x 0.98

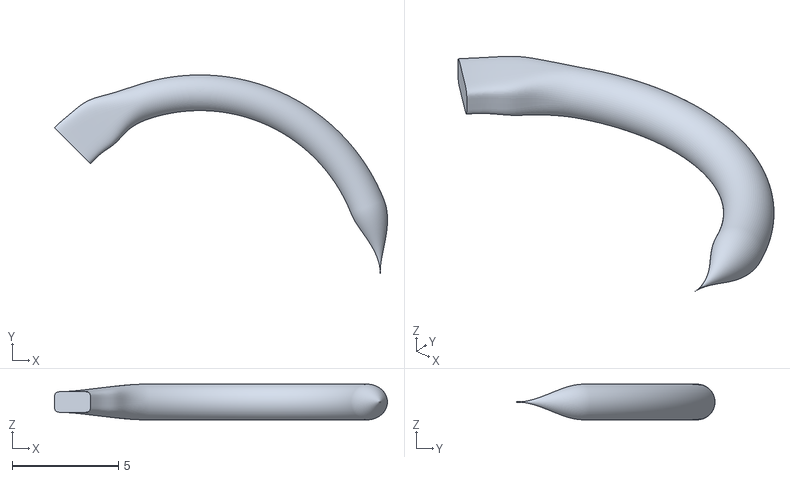
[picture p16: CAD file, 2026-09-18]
asset/needle_20mm_135deg_1p68mm_flat_keyed_tail.stl
15.7 x 9.33 x 1.68

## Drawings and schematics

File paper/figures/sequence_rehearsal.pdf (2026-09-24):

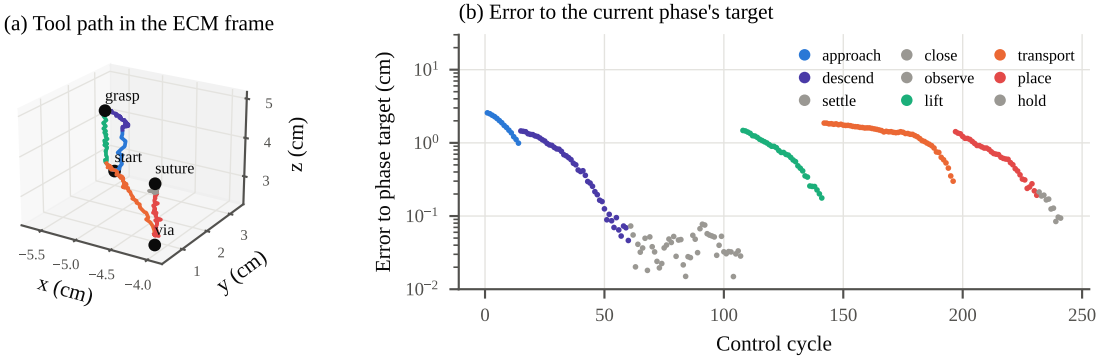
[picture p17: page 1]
start; grasp; via; suture; Control cycle; approach descend settle; close observe lift; transport place hold

(a) Tool path in the ECM frame

(b) Error to the current phase's target

Error to phase target (cm)

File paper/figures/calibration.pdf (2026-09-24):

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

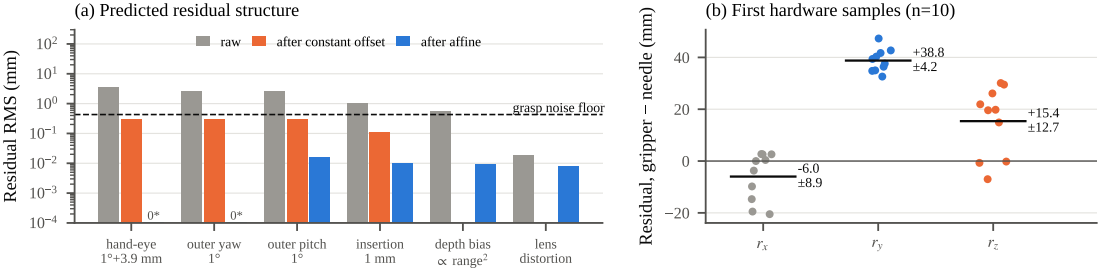
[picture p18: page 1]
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

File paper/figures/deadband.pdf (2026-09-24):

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

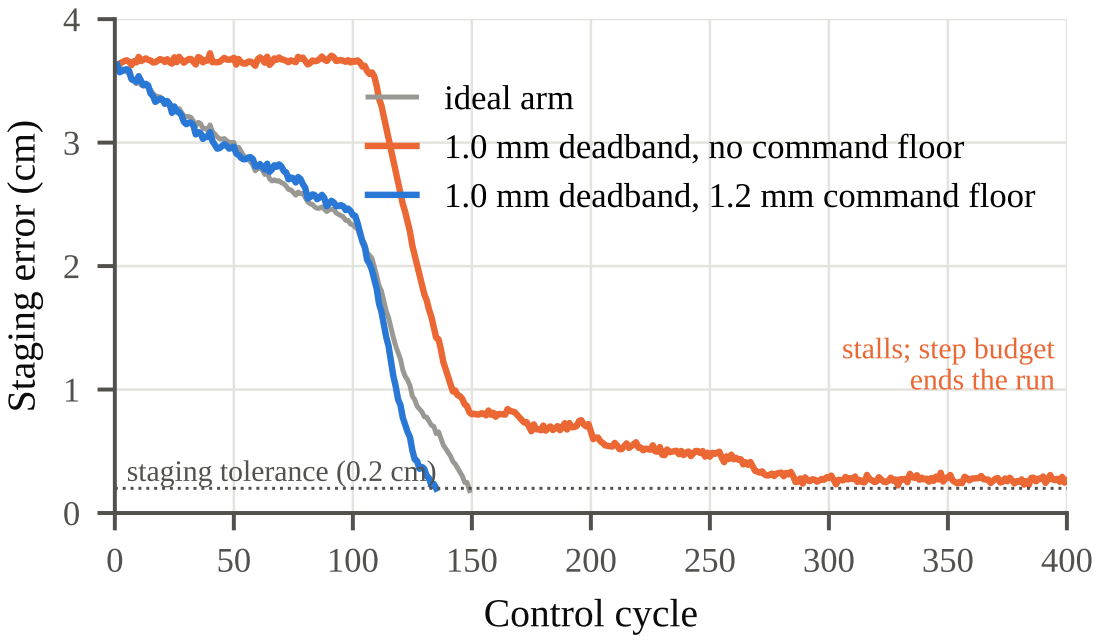
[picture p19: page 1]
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

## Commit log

2026-09-15 Add grasp and lift to the real-robot deployment
    Extends the approach deployment to approach -> close the jaw -> observe ->
    lift 1.5 cm, on real dVRK hardware. The approach path is untouched: the same
    ApproachLoop, the same verified 21-dim observation contract, the same
    rl/d2/residual choice.
    There is no grasp sensor on a real PSM. In simulation the environment calls
    psm.actuators[0].actuate("Needle") and grasp_status()["needle_grasped"] is
    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
2026-09-15 Fix jaw QoS mismatch and make dry runs show the sequence
    Two problems found on the first dry run against lcsr-dvrk-15.
    The node reported "nothing on /PSM1/jaw/measured_js" while ros2 topic echo on
    the same name returned a full message, effort field included. Cause: the
    subscription asked for RELIABLE, and a RELIABLE subscriber never matches a
    BEST_EFFORT publisher. measured_cp matched, the jaw topic did not, so the jaw
    was silently unmonitored on an arm that does publish it. Subscriptions now
    default to BEST_EFFORT, which matches publishers of either kind
    (--sub-reliability to override); command publishers stay RELIABLE. Both the
    probe and the node now also wait for the first jaw message ra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
2026-09-15 Validate the jaw baseline instead of crashing on it
    A missing --jaw-baseline file raised a FileNotFoundError traceback out of
    main(). Baseline loading now returns a message and exit code 3, and the message
    says how to create the file.
    While fixing that, three ways a baseline can be present but untrustworthy are
    now refused rather than accepted, because every jaw reading in the run is
    compared against it and a bad reference produces evidence that is wrong while
    still looking authoritative:
    - recorded in a dry run, where the jaw never moved and the numbers describe
    wherever it already was (calibrate_jaw.py already records executed=false);
    - recorded closing to a different angle than the ru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
2026-09-15 Log the R6 support as information under the geometric servo
    The precheck says the R6 trained region does not bound controller 'd2', and
    the node then logged the same numbers as a WARN a few lines later. On a live
    arm a warning should mean "consider stopping", not "here is a figure that does
    not apply to the controller you chose" -- which is how it read on lcsr-dvrk-15,
    where a 4.6 deg wrist rotation was flagged against the policy's 25.7-100.2 deg
    demonstration range during a d2 run.
    The support block is now a WARN only under rl/residual, where it describes a
    real failure mode, and an INFO labelled "for reference only" otherwise. Nothing
    about the check itself changed; only which controllers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
2026-09-15 Solve for a start pose inside the R6 training support
    Until now the RL path could only be reported as out of distribution. The two
    support constraints are on the relative geometry between start and grasp:
    tool offset R_start^T (p_grasp - p_start) in the demonstration box
    rotation geodesic(R_start, R_grasp) in [25.7, 100.2] deg
    and both are invariant under the frame bridge -- a rigid X cancels in the tool
    offset and leaves a geodesic unchanged -- so with the grasp pose fixed they can
    be satisfied by choosing the start pose in the robot's own frame:
    R_start = R_grasp * Rel^-1 Rel = the mean start->goal rotation (57.1 deg)
    p_start = p_grasp - R_start * offse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
2026-09-15 Check the checkpoint path before importing torch
    ApproachPolicy.load imported stable_baselines3 first, so a wrong --model path
    surfaced as ModuleNotFoundError for stable_baselines3 -- which points at a
    two-gigabyte install as the fix for a typo. The path is now checked first, and
    a relative path that misses says what it was resolved against and where the
    checkpoint normally lives (models/rl at the repository root, so ../models/rl
    from deploy/).
    A genuinely missing stable-baselines3 now exits with the venv and CPU-wheel
    commands rather than a bare import traceback, and notes that --controller d2
    needs none of it.
    166 tests.
2026-09-15 Sweep the R6 support, and let the jaw be set offline
    The first in-support test on lcsr-dvrk-15 came back negative: from a start pose
    verified INSIDE the demonstration support, the policy still ran to max_steps,
    closest approach 0.87 cm against 0.85-0.98 cm from the out-of-distribution
    starts. Being in distribution changed nothing. The trace shows it rotating
    correctly for eleven steps, reversing at step 12, then settling into a limit
    cycle that walks the translation error back out from 0.87 cm to 3.6 cm.
    One sample is not a result, so tools/sweep_r6_support.py grids the offset box,
    sweeps the rotation and the jaw, asserts every start is in support before using
    it, and runs the servo from th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
2026-09-15 Fix the RPY branch defect that broke every RL run
    The released checkpoints diverged to ~130 deg of orientation error from every
    start, in distribution or out. The cause was here, not in the policies.
    A rotation matrix is branch-invariant; the RPY triple describing it is not.
    scipy's as_euler("xyz") returns roll and yaw in [-pi, pi]. The SurgicAI
    environments integrate the RPY vector as free state and never re-canonicalize
    it, and in the upstream Approach checkpoint 100% of desired-goal rolls and 85%
    of achieved-goal rolls lie OUTSIDE [-pi, pi]:
    training goal rpy [-3.774 0.497 1.317]
    after matrix round-trip [ 2.509 0.497 1.317] difference exactly 2*pi
    ApproachLoop re-de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
2026-09-15 Measure the contract instead of assuming it, and fix what that found
    Replaying the upstream Approach checkpoint from its own demonstration
    starts, in the training frame, against a perfect arm, is a test this
    package never had. tools/replay_demos.py adds it, and it immediately
    disagreed with almost everything the constants said.
    Three defects, each read out of SurgicAI's sources rather than guessed:
    1. The roll branch. subtask_env.Frame2Vec(bound=True) forces roll into
    (-2pi, 0]; scipy hands back [-pi, pi]. frames.bound_roll() is now a
    transcription of that rule, and it reproduces 50/50 stored goal rolls
    and 50/50 stored start rolls without being told the branch. The old
    unwrap-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
2026-09-15 Carry the needle to the suturing point
    The sequence becomes stage -> approach -> settle -> close -> observe ->
    lift -> transport -> place -> hold, driven off the plan rather than
    hard-coded: a plan with no staging pose starts at the approach, one with
    no suturing pose still stops after the lift, and Insert or Pullout drop
    in as two more segments if anyone ever decides that is safe.
    stage
    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
2026-09-15 Give the pipeline a command line
    run_pipeline.py takes the three poses the task is actually described by
    -- where the arm is (read from the arm), where the gripper must be to
    take the needle, and where the gripper must be for the needle to sit
    angled at the entry point -- and the node and the offline rehearsal tool
    now share the same surface, so what you rehearse is what you run.
    --suture-pos/--suture-quat the placing leg. Tool poses, not needle
    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
2026-09-15 Document what the measurements actually say
    The grasp-lift guide becomes the pipeline guide: three tool poses in,
    eight phases out, with the transport going over the top rather than
    straight there and the reason why.
    The contract sections are rewritten around evidence instead of
    inference. The roll branch is now a transcription of Frame2Vec rather
    than a heuristic, with the 50/50 recovery rate. The action-scale section
    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
2026-09-16 Measure the workspace question instead of arguing about it
    "Can we extend the workspace" turns out to be the wrong question for the
    approach leg, and tools/workspace_spec.py says so with numbers.
    A goal-conditioned policy's support, as read off its demonstrations, is
    expressed entirely in relative quantities -- the tool-frame offset from
    start to goal, and the geodesic rotation between them -- and both are
    invariant under any rigid transform. So any grasp pose can be brought
    inside the support by choosing the start pose. Over the +-3 mm / +-30 deg
    needle placement envelope this repository already assumes, on the real
    recorded geometry:
    in support without staging 0/400
    in support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
2026-09-16 A retraining plan that says what retraining is actually for
    RL/RETRAINING.md and RL/curriculum.py, written after measuring the
    released checkpoints rather than before.
    The headline is negative and worth having: for the approach leg the
    trained support is not what limits this task. Staging covers 400/400 of
    the needle envelope with a 3.7 cm move, so a retrain aimed at "a wider
    workspace" would buy nothing. What it would buy is three other things,
    and the document separates them:
    * start-pose robustness. The released demos contain ONE distinct start
    pose across fifty episodes, and Approach_env.reset has the
    randomisation written out and commented. Low_level_env_complete.reset
    c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
2026-09-16 Stop the safety layer from re-closing the loop it was meant to guard
    Found by rehearsing the pipeline against a mock arm that closes half the
    commanded gap per cycle: the RL approach aborted after twelve consecutive
    step_rotation clamps, on geometry that succeeds against a perfect arm.
    The per-step caps were measured against the MEASURED pose. Under the
    open-loop observation contract the command legitimately runs ahead of a
    lagging arm, so the cap fired every cycle and dragged the command back
    toward the arm -- which is exactly the closed loop the open-loop fix
    removed, reintroduced through the safety layer, where nobody would look
    for it.
    The caps now bound consecutive commands, which is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
2026-09-16 R6 acts at 1.0 mm, not 1.5 mm
    Replayed on lcsr-dvrk-15 against its own 50 demonstration starts, at its
    own tolerance, against a perfect arm:
    0.5 mm / 2 deg 24/50 48%
    0.5 mm / 3 deg 23/50 46%
    1.0 mm / 2 deg 35/50 70%
    1.0 mm / 3 deg 46/50 92% <--
    1.5 mm / 3 deg 36/50 72% <-- what this package applied
    2.0 mm / 2 deg 10/50 20%
    R6 inherited upstream's training scale after all. The 1.5 mm came from
    this repository's own RL/utils/utils.py and had never been checked against
    the policy, only against the training sources that produced it. Every R6
    result recorded in this project was therefore taken 50% over scale in
    translation, including last week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
2026-09-16 Report the descent as vertical, because it is
    The precheck announced "lateral drift during the descent 3.000 cm" on a
    plan whose descent is purely vertical by construction -- the via point is
    the suturing pose displaced along the lift axis, so there is nothing to
    drift.
    A sign error: it added the component along the lift axis instead of
    subtracting it, which turns a purely parallel descent into twice itself.
    The number was always exactly 2x the lift distance and never meant
    anything. Worse than useless on a live run: it is the one line in the
    precheck that would tell an operator the needle is about to come down
    three centimetres off target.
    Two tests, one that the vertical case reads zero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
2026-09-16 The policy's goal is 7 mm short of the needle, so stop there
    scene_manager.needle_goal_evaluator builds the Approach goal as
    needle_pose(grasp_angle) * translate(0, 0, lift_height) * R_fixed
    with lift_height = 0.007 and R_fixed flipping the tool z axis. The goal is
    therefore the grasp point backed off 7 mm along the gripper's own axis,
    with the jaws pointing at it. The trained policy never drives into the
    needle; it flies to a hover point and stops.
    In simulation the grasp is then faked -- actuators[0].actuate("Needle")
    attaches the needle wherever the jaws happen to be -- so nothing in
    training ever had to travel that last 7 mm, and nothing noticed. This
    package was sending the polic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
2026-09-16 Correct a taught suturing pose for where the jaws actually closed
    With no needle-pose estimate on this setup, every pose is taught by
    jogging -- and a suturing pose recorded that way silently encodes how the
    needle sat in the jaws at that moment. Close the jaws a millimetre
    elsewhere and the placement is wrong by a millimetre, with nothing in the
    run saying so.
    The correction is exact. With W the needle's pose in the world, E where
    the needle must end up and N = G^-1 W how it sits in the jaws, a tool pose
    S puts the needle at S N, so reaching E needs S = E W^-1 G. Taught with
    G_t and grasping at G_a:
    S_a = S_t * G_t^-1 * G_a
    and both E and W cancel -- neither the needle pose nor the e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
2026-09-16 Stop a keyword landing on the wrong call site
    TypeError: precheck() got an unexpected keyword argument
    'compensate_suture'
    on a real arm, on the first dry run. The suturing-compensation options
    belong on SequenceConfig; a text substitution that was meant for that
    call matched the precheck call too, because both spell their arguments
    the same way. The offline tool escaped only because its two call sites
    phrase them differently, so the end-to-end test that exists for the tool
    proved nothing about the node.
    The gap is structural: the node's main() needs rclpy and a robot, so no
    test executes any of it, and any call-site drift in it ships.
    Two static guards, which need neither:
    * e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
2026-09-16 Make the operator gate visible
    On the first real dry run the arm closed the jaw, stopped, and printed
    "JAW IS CLOSED. The lift is waiting for you." exactly once -- then buried
    it under a 10 Hz status line. Within seconds the only thing on screen was
    a stationary arm repeating itself at 0.00 cm, and it read as a hang. The
    gate is the one place in this package where a human is load-bearing, and
    it was the one message that scrolled away.
    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
2026-09-16 Ask the arm one question instead of guessing for two minutes
    Live bring-up on lcsr-dvrk-15: the staging move sat at 0.25 cm of error
    for 49 cycles without the arm moving at all. "The arm does not move" has
    several very different causes that look identical from inside a control
    loop -- nothing subscribed to the command topic, an arm enabled but not
    homed, a frame mismatch between what measured_cp reports and what
    servo_cp expects, another component holding the setpoint -- and a loop
    that keeps issuing commands cannot tell them apart. Two additions so the
    software answers what it can.
    tools/poke_arm.py reads measured_cp, publishes ONE setpoint a couple of
    millimetres away, and reports whether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
2026-09-16 A real arm has a deadband; an ideal integrator does not
    On lcsr-dvrk-15 the staging move sat at 0.25 cm of error for 49 cycles.
    The arm was enabled, homed and idle, dvrk was subscribed to servo_cp, and
    a hand-published 2 mm setpoint moved it 1.947 mm. What the loop was
    publishing was 0.4 mm a cycle, because a proportional servo shrinks its
    step near the goal and R6's step size is 1.0 mm. The arm ignored it.
    Nothing detected this. The tracking guard had nothing to say -- the
    command was never more than 0.4 mm ahead of the arm -- so the run neither
    converged nor aborted, and only the step budget would ever have ended it.
    This is a sim2real gap of the same family as the others in this package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
2026-09-17 Learn the grasp residual the geometry cannot supply
    Adds the two-stage calibration of the task description: FoundationPose plus
    the fitted hand-eye transform as the coarse stage, and a Bernstein residual
    field, fitted to hand-taught successful grasps, as the fine one. Following
    Xiao et al. (ISMR 2022), with two departures that the numbers argue for.
    The first is that the model family starts below linear. A trivariate
    polynomial of total degree n lives inside the tensor-product Bernstein space
    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
2026-09-17 Say how many placements it takes, instead of guessing
    The detection sweep, six seeds per cell against a 1 mm curved bias and a
    0.43 mm floor: 2/6 at twenty placements, 5/6 at thirty, 6/6 from forty-five on,
    and zero false positives at every size. The false-positive column is the one
    that matters -- the procedure does not invent curvature -- and forty-five is
    where it starts reliably finding curvature that is there. Sixty is the
    recommendation: past the knee, with room for the placements a pose flip costs.
    Four lucky seeds had previously reported 100% at twenty, so the power
    sub-command now defaults to eight and says why.
    Also fixes the audit crashing on exactly the dataset it exists to d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
2026-09-24 Add draft paper (prepared for publication)
    Draft manuscript covering the hierarchical SurgicAI replication on ROS 2,
    the real-dVRK perception front end, the deployment contract and its three
    defects, staging, the guarded phase machine, the deadband finding and the
    two-stage grasp calibration. PDF, LaTeX source, figure script and the
    rehearsal traces the figures are drawn from are in paper/. Linked from the
    top of README.md.
2026-09-24 Rewrite the README around the current pipeline; add corresponding authors
    The README described the perception-and-Reach entry point of a different
    repository (scripts/, configs/, ros2_ws/ are not in this tree). It now
    describes what is here: the real-robot pipeline from staging to place, the
    grasp calibration, the simulation environments, the eight contract and
    hardware findings a user must know before running anything, the run order
    on hardware, and where the perception code and the hierarchical
    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
